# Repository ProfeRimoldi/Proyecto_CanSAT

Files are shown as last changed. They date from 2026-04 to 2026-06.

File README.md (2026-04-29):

# Proyecto CanSat – Base Aérea El Palomar

Sistema electrónico para misión tipo CanSat desarrollado en la EEST N°4 I Brigada Aérea El Palomar, orientado al diseño, validación y documentación de hardware y firmware para sistemas embarcados aeroespaciales.

Este repositorio centraliza el desarrollo de:

* Onboard Computer (OBC)
* Earth Station Dev Board
* Firmware ESP32
* Documentación técnica
* Revisiones de fabricación de PCB

---

## Estructura del proyecto

```text
Proyecto_CanSAT/
├── hardware/
│   ├── Onboard_Comp/
│   │   ├── kicad/
│   │   ├── outputs/
│   │   │   └── Rev_A/
│   │   └── docs/
│   │
│   └── Earth_Station/
│       ├── kicad/
│       ├── outputs/
│       └── docs/
│
├── firmware/
│
├── docs/
│
└── README.md
```

---

## Hardware

### Onboard Computer (OBC)

Computadora principal embarcada encargada de:

* adquisición de sensores
* telemetría
* control de misión
* gestión de eventos de vuelo
* integración con estación terrestre

Actualmente cuenta con:

* diseño PCB en KiCad
* esquemático jerárquico
* revisión formal de fabricación `Rev_A`
* Gerbers
* Drill files
* BOM
* PDF de esquemático
* renders e imágenes técnicas

---

### Earth Station Dev Board

Placa de desarrollo para estación terrestre destinada a:

* recepción de telemetría
* configuración de parámetros
* validación de comunicaciones
* integración de subsistemas

Actualmente cuenta con:

* diseño PCB en KiCad
* documentación estructurada
* revisión formal de fabricación `Rev_A`
* Gerbers
* Drill files
* BOM
* PDF de esquemático
* renders e imágenes técnicas

---

## Firmware

Desarrollo basado en ESP32 para:

* adquisición de datos
* control de sensores
* comunicaciones
* telemetría
* lógica de misión

Actualmente cuenta con:

* Firmware Test, verificador de enlace de comunicación LoRa entre los módulos.
* Muestra en pantalla, firmware dedicado a enviar los datos de aceleración en 3 ejes, y un código en Processing para visualizarlo.
* TestLED, para verificar el funcionamiento de los periféricos en la Earth Station Dev Board.

La estructura de firmware se encuentra en evolución y será versionada junto con las revisiones de hardware.

---

## Gestión de revisiones

Las revisiones de fabricación se organizan mediante:

```text
outputs/Rev_A/
outputs/Rev_B/
outputs/Rev_C/
```

permitiendo trazabilidad completa entre:

* diseño fuente
* fabricación real
* validaciones de laboratorio
* mejoras de revisión

---

## Objetivo

Mantener una metodología de desarrollo profesional para proyectos electrónicos aeroespaciales, con trazabilidad completa de hardware, firmware y documentación técnica.

---

## Autor

Damián Rimoldi
Ingeniería Electrónica – UTN FRH
GLT – Grupo de Lanzadores Tecnológicos
EEST N°4 I Brigada Aérea El Palomar

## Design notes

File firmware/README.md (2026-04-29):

# Firmware – Proyecto CanSat

Esta carpeta contiene el desarrollo de firmware y software auxiliar utilizado para validación, pruebas de laboratorio y futuras implementaciones del sistema CanSat.

Actualmente se incluyen códigos base, pruebas funcionales y herramientas de visualización para distintos subsistemas del proyecto.

---

## Contenido actual

```text
firmware/
├── EMISOR.ino
├── RECEPTOR.ino
├── CodBase.ino
├── TestLED.ino
├── Ver1.pde
└── README.md
```

---

## Descripción de archivos

---

### EMISOR.ino

Código de prueba para transmisión LoRa utilizando ESP32 + módulo SX1278 (433 MHz).

### Función

Permite enviar datos por comunicación LoRa desde la estación emisora hacia el receptor.

### Características

* inicialización de módulo LoRa
* frecuencia configurada en 433 MHz
* transmisión de mensajes desde monitor serie
* envío automático de secuencia numérica incremental
* validación básica de enlace inalámbrico

### Objetivo

Verificar estabilidad y alcance inicial de la comunicación LoRa entre nodos.

---

### RECEPTOR.ino

Código de prueba para recepción LoRa utilizando ESP32 + módulo SX1278 (433 MHz).

### Función

Recibe paquetes enviados por el transmisor y los muestra por puerto serie.

### Características

* inicialización de receptor LoRa
* recepción de paquetes
* reconstrucción de mensajes
* monitoreo por Serial Monitor

### Objetivo

Validar la recepción correcta de telemetría y pruebas de enlace.

---

### CodBase.ino

Código base para adquisición de datos utilizando sensor MPU6050 + ESP32.

### Función

Lee aceleración y velocidad angular del MPU6050 y transmite los datos por puerto serie.

### Características

* lectura de acelerómetro
* lectura de giroscopio
* integración temporal de velocidades angulares
* cálculo de ángulos acumulados
* envío de datos seriales en formato CSV

### Variables transmitidas

* aceleración X
* aceleración Y
* aceleración Z
* ángulo X
* ángulo Y
* ángulo Z

### Objetivo

Base de pruebas para sistemas de navegación, orientación e inclinación del vehículo.

---

### Ver1.pde

Visualización 3D en Processing para representación de orientación del sistema.

### Función

Recibe datos seriales desde el ESP32 y representa gráficamente la inclinación del cohete en tiempo real.

### Características

* comunicación serial con Processing
* lectura de datos CSV
* suavizado mediante filtro simple
* representación 3D con entorno P3D
* simulación visual del movimiento del cohete

### Objetivo

Visualizar rápidamente el comportamiento dinámico del sistema durante pruebas de sensores.

---

### TestLED.ino

Código de testeo funcional para la Earth Station Dev Board.

### Función

Permite verificar salidas digitales, buzzer, relay y conexiones principales de la placa.

### Características

* test secuencial de GPIOs
* activación progresiva de pines
* validación visual y sonora
* múltiples velocidades de prueba
* chequeo de líneas asociadas a GPS, MPU, buzzer y relay

### Objetivo

Confirmar funcionamiento eléctrico inicial de la placa fabricada.

---

## Próximas etapas

El firmware definitivo evolucionará hacia:

* máquina de estados de misión
* adquisición de sensores de vuelo
* altimetría
* detección de eventos (ignición, apogeo, despliegue)
* telemetría LoRa
* almacenamiento de datos
* comunicación con estación terrestre
* lógica de seguridad redundante

---

## Objetivo general

Mantener trazabilidad y evolución progresiva del firmware desde pruebas iniciales hasta la versión final de vuelo.

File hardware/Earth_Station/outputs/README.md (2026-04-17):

# Outputs - Earth Station

Esta carpeta contiene los archivos de fabricación y exportación del PCB de la Earth Station Dev Board.

## Estructura

### Rev_A

Primera revisión formal de fabricación de la placa.

Contenido esperado:

- Gerbers
- Drill files
- PDF del esquemático
- Imágenes del PCB
- BOM (Bill of Materials)

## Notas

Solo deben guardarse aquí versiones consolidadas listas para fabricación o revisión formal.

No utilizar esta carpeta para archivos temporales, backups automáticos o pruebas intermedias.

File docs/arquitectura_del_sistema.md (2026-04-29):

# Arquitectura del Sistema – Proyecto CanSat

## 1. Descripción general

El sistema CanSat se organiza en dos bloques principales:

* Onboard Computer (OBC)
* Earth Station Dev Board

El OBC corresponde al sistema embarcado, encargado de adquirir datos, procesar información de sensores, ejecutar la lógica de misión y transmitir telemetría.

La Earth Station Dev Board corresponde al sistema de tierra, orientado a recibir datos, visualizar información, validar comunicaciones y asistir durante pruebas de laboratorio o campo.

---

## 2. Bloques principales

### 2.1 Onboard Computer

Funciones principales:

* adquisición de sensores
* procesamiento de datos
* comunicación inalámbrica
* gestión de eventos de misión
* almacenamiento o transmisión de telemetría
* integración con firmware ESP32

### 2.2 Earth Station Dev Board

Funciones principales:

* recepción de telemetría
* monitoreo de datos
* pruebas de enlace LoRa
* asistencia durante validaciones
* interfaz con computadora o sistema de visualización

---

## 3. Arquitectura funcional

```text
[Sensores] 
    ↓
[Onboard Computer - ESP32]
    ↓
[Comunicación LoRa]
    ↓
[Earth Station Dev Board]
    ↓
[PC / Visualización / Registro]
```

---

## 4. Relación hardware-firmware

El hardware proporciona las interfaces físicas necesarias para sensores, comunicación, alimentación y señales auxiliares.

El firmware define el comportamiento lógico del sistema, incluyendo:

* inicialización de periféricos
* lectura de sensores
* procesamiento de datos
* comunicación LoRa
* lógica de misión
* gestión de estados
* transmisión de telemetría

---

## 5. Estado actual

Actualmente el proyecto cuenta con:

* PCB del Onboard Computer fabricada y documentada como `Rev_A`
* PCB de Earth Station fabricada y documentada como `Rev_A`
* firmware de prueba para LoRa, sensores y visualización
* validación de comunicación LoRa
* documentación inicial de arquitectura y trazabilidad

---

## 6. Próximas etapas

Las próximas etapas técnicas incluyen:

* consolidar firmware base
* definir máquina de estados de misión
* integrar sensores principales
* registrar pruebas de laboratorio
* documentar cambios entre revisiones
* avanzar hacia una versión estable de vuelo

---

## 7. Objetivo de arquitectura

Definir una estructura clara que permita evolucionar el sistema desde pruebas parciales hacia un sistema integrado, manteniendo trazabilidad entre diseño electrónico, firmware, fabricación y validación experimental.

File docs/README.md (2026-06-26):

# Documentation – Proyecto CanSat

Esta carpeta contiene la documentación técnica principal del proyecto, incluyendo arquitectura general del sistema, criterios de diseño, requerimientos, validaciones y evolución del desarrollo.

Aquí se concentra la trazabilidad técnica global entre hardware, firmware y validaciones experimentales.

---

## Contenido esperado

* arquitectura general del sistema
* requerimientos funcionales
* máquina de estados de misión
* plan de validación y ensayos
* decisiones de diseño
* criterios de seguridad
* cronograma de desarrollo
* informes técnicos.
* documentación de revisiones.

---

## Objetivo

Mantener una metodología de desarrollo profesional orientada a proyectos electrónicos aeroespaciales, permitiendo reconstruir decisiones técnicas, justificar revisiones y facilitar futuras iteraciones del sistema.

La documentación debe acompañar al hardware y firmware, no aparecer únicamente al final del proyecto.

---

## Relación con otras carpetas

* `hardware/` → diseño fuente y fabricación de PCB
* `firmware/` → desarrollo de software embbido
* `docs/` → documentación técnica global del sistema

---

## Nota importante

Cada cambio importante de hardware o firmware deberás tener su respaldo técnico correspondiente en esta carpeta.

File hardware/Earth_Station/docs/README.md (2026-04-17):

# Documentation - Earth Station

Esta carpeta contiene documentación técnica complementaria del proyecto.

## Contenido esperado

- decisiones de diseño
- notas de ingeniería
- cambios importantes entre revisiones
- cálculos relevantes
- validaciones y pruebas
- observaciones de fabricación
- incidencias detectadas en laboratorio

## Objetivo

Mantener trazabilidad técnica del desarrollo del hardware y facilitar futuras revisiones o rediseños.

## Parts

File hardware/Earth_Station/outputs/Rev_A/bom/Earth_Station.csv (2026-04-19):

Reference | Value | Datasheet | Footprint | Qty | DNP
BZ1 | Buzzer |  | Buzzer_Beeper:Buzzer_TDK_PS1240P02BT_D12.2mm_H6.5mm | 1
C1,C4,C5,C6 | 100nF |  | Capacitor_SMD:C_0805_2012Metric | 4
C2 | 100uF |  | Capacitor_SMD:CP_Elec_5x3 | 1
C3 | 10uF |  | Capacitor_SMD:CP_Elec_5x3.9 | 1
D1,D2,D3,D4,D5,D6,D7,D8,D9,D11 | LED |  | LED_SMD:LED_0805_2012Metric_Pad1.15x1.40mm_HandSolder | 10
D10 | 1N4148 | https://assets.nexperia.com/documents/data-sheet/1N4148_1N4448.pdf | Diode_THT:D_DO-35_SOD27_P7.62mm_Horizontal | 1
D12 | SS34 | https://www.vishay.com/docs/88751/ss32.pdf | Diode_SMD:D_3220_8050Metric_Pad2.65x5.15mm_HandSolder | 1
esp1,esp32_1 | Conn_01x19_Pin |  | Connector_PinSocket_2.54mm:PinSocket_1x19_P2.54mm_Vertical | 2
J1,J9 | SOCKET_UP |  | Connector_PinSocket_2.54mm:PinSocket_1x02_P2.54mm_Vertical,Connector_PinSocket_2.54mm:PinSocket_1x12_P2.54mm_Vertical | 2
J2 | Screw_Terminal_01x03 |  | TerminalBlock:TerminalBlock_bornier-3_P5.08mm | 1
J3,J5 | Conn_01x08 |  | Connector_PinSocket_2.54mm:PinSocket_1x08_P2.54mm_Vertical | 2
J4,J8,J12 | PLACA |  | Connector_PinHeader_1.27mm:PinHeader_1x02_P1.27mm_Vertical,Connector_PinHeader_1.27mm:PinHeader_1x12_P1.27mm_Vertical | 3
J6 | Conn_01x04 |  | Connector_PinSocket_2.54mm:PinSocket_1x04_P2.54mm_Vertical | 1
J7 | HEADER_DOWN |  | Connector_PinHeader_2.54mm:PinHeader_1x02_P2.54mm_Vertical | 1
J15 | Screw_Terminal_01x02 |  | TerminalBlock:TerminalBlock_bornier-2_P5.08mm | 1
J16 | Conn_01x02 |  | Connector_PinSocket_2.54mm:PinSocket_1x02_P2.54mm_Vertical | 1
K1 | Relay_SPDT |  | Relay_THT:Relay_SPDT_Finder_36.11 | 1
Q1 | NPN | https://ngspice.sourceforge.io/docs/ngspice-html-manual/manual.xhtml#cha_BJTs | Package_TO_SOT_THT:TO-92L_Inline | 1
R1,R2,R3,R4,R5,R6,R7,R8,R9,R10,R11,R12,R15 | 1K |  | Resistor_SMD:R_0805_2012Metric_Pad1.20x1.40mm_HandSolder | 13
R13,R14 | R |  | Resistor_SMD:R_0805_2012Metric,Resistor_SMD:R_0805_2012Metric_Pad1.20x1.40mm_HandSolder | 2
SW1 | SW_SPDT |  | Button_Switch_THT:SW_Slide_SPDT_Straight_CK_OS102011MS2Q | 1
SW2,SW3,SW4 | SW_Push_Dual |  | Button_Switch_SMD:SW_Push_1P1T_NO_Vertical_Wuerth_434133025816 | 3
U1,U2 | LM324A | http://www.ti.com/lit/ds/symlink/lm2902-n.pdf | Package_SO:SOIC-14_3.9x8.7mm_P1.27mm | 2
U3 | L7805 | http://www.st.com/content/ccc/resource/technical/document/datasheet/41/4f/b3/b0/12/d4/47/88/CD00000444.pdf/files/CD00000444.pdf/jcr:content/translations/en.CD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 | Package_TO_SOT_SMD:TO-263-2 | 1

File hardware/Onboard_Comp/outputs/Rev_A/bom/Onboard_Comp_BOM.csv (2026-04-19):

Reference | Value | Datasheet | Footprint | Qty | DNP
BZ1 | Buzzer |  | Buzzer_Beeper:Buzzer_TDK_PS1240P02BT_D12.2mm_H6.5mm | 1
C1 | 100nF |  | Capacitor_SMD:C_0805_2012Metric | 1
C2 | 100uF |  | Capacitor_SMD:CP_Elec_5x3.9 | 1
C3 | C_Polarized_Small |  | Capacitor_SMD:C_0805_2012Metric | 1
D1 | LED |  | LED_SMD:LED_0805_2012Metric_Pad1.15x1.40mm_HandSolder | 1
esp1,esp32_1 | Conn_01x19_Pin |  | Connector_PinSocket_2.54mm:PinSocket_1x19_P2.54mm_Vertical | 2
J1,J5,J9 | SOCKET_UP |  | Connector_PinSocket_2.54mm:PinSocket_1x02_P2.54mm_Vertical,Connector_PinSocket_2.54mm:PinSocket_1x12_P2.54mm_Vertical | 3
J2,J6,J10 | HEADER_UP |  | Connector_PinHeader_2.54mm:PinHeader_1x02_P2.54mm_Vertical,Connector_PinHeader_2.54mm:PinHeader_1x12_P2.54mm_Vertical | 3
J3,J7,J11 | HEADER_DOWN |  | Connector_PinHeader_2.54mm:PinHeader_1x02_P2.54mm_Vertical,Connector_PinHeader_2.54mm:PinHeader_1x12_P2.54mm_Vertical | 3
J4,J8,J12 | PLACA |  | Connector_PinHeader_1.27mm:PinHeader_1x02_P1.27mm_Vertical,Connector_PinHeader_1.27mm:PinHeader_1x12_P1.27mm_Vertical | 3
J13 | Conn_01x08_SocketMPU |  | Connector_PinSocket_2.54mm:PinSocket_1x08_P2.54mm_Vertical | 1
J14 | Conn_01x04_Socket |  | Connector_PinSocket_2.54mm:PinSocket_1x04_P2.54mm_Vertical | 1
J15 | Screw_Terminal_01x02 |  | TerminalBlock:TerminalBlock_bornier-2_P5.08mm | 1
J16,J18,J20,J21 | Conn_01x02 |  | Connector_PinHeader_2.54mm:PinHeader_1x02_P2.54mm_Vertical,Connector_PinSocket_2.54mm:PinSocket_1x02_P2.54mm_Vertical | 4
J17 | Conn_01x06_Socket |  | Connector_PinSocket_2.54mm:PinSocket_1x06_P2.54mm_Vertical | 1
J19 | Conn_01x03 |  | Connector_PinSocket_2.54mm:PinSocket_1x03_P2.54mm_Vertical | 1
R1 | 1K |  | Resistor_SMD:R_0805_2012Metric | 1
R2 | R |  | Resistor_SMD:R_0805_2012Metric_Pad1.20x1.40mm_HandSolder | 1
SW1 | SW_SPDT |  | Button_Switch_THT:SW_Slide_SPDT_Straight_CK_OS102011MS2Q | 1
U1 | 25CSM04xxSN | https://ww1.microchip.com/downloads/aemDocuments/documents/MPD/ProductDocuments/DataSheets/25CSM04-4-Mbit-SPI-Serial-EEPROM-With-128-Bit-Serial-Number-and-Enh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 | Package_SO:SOIC-8_5.23x5.23mm_P1.27mm | 1

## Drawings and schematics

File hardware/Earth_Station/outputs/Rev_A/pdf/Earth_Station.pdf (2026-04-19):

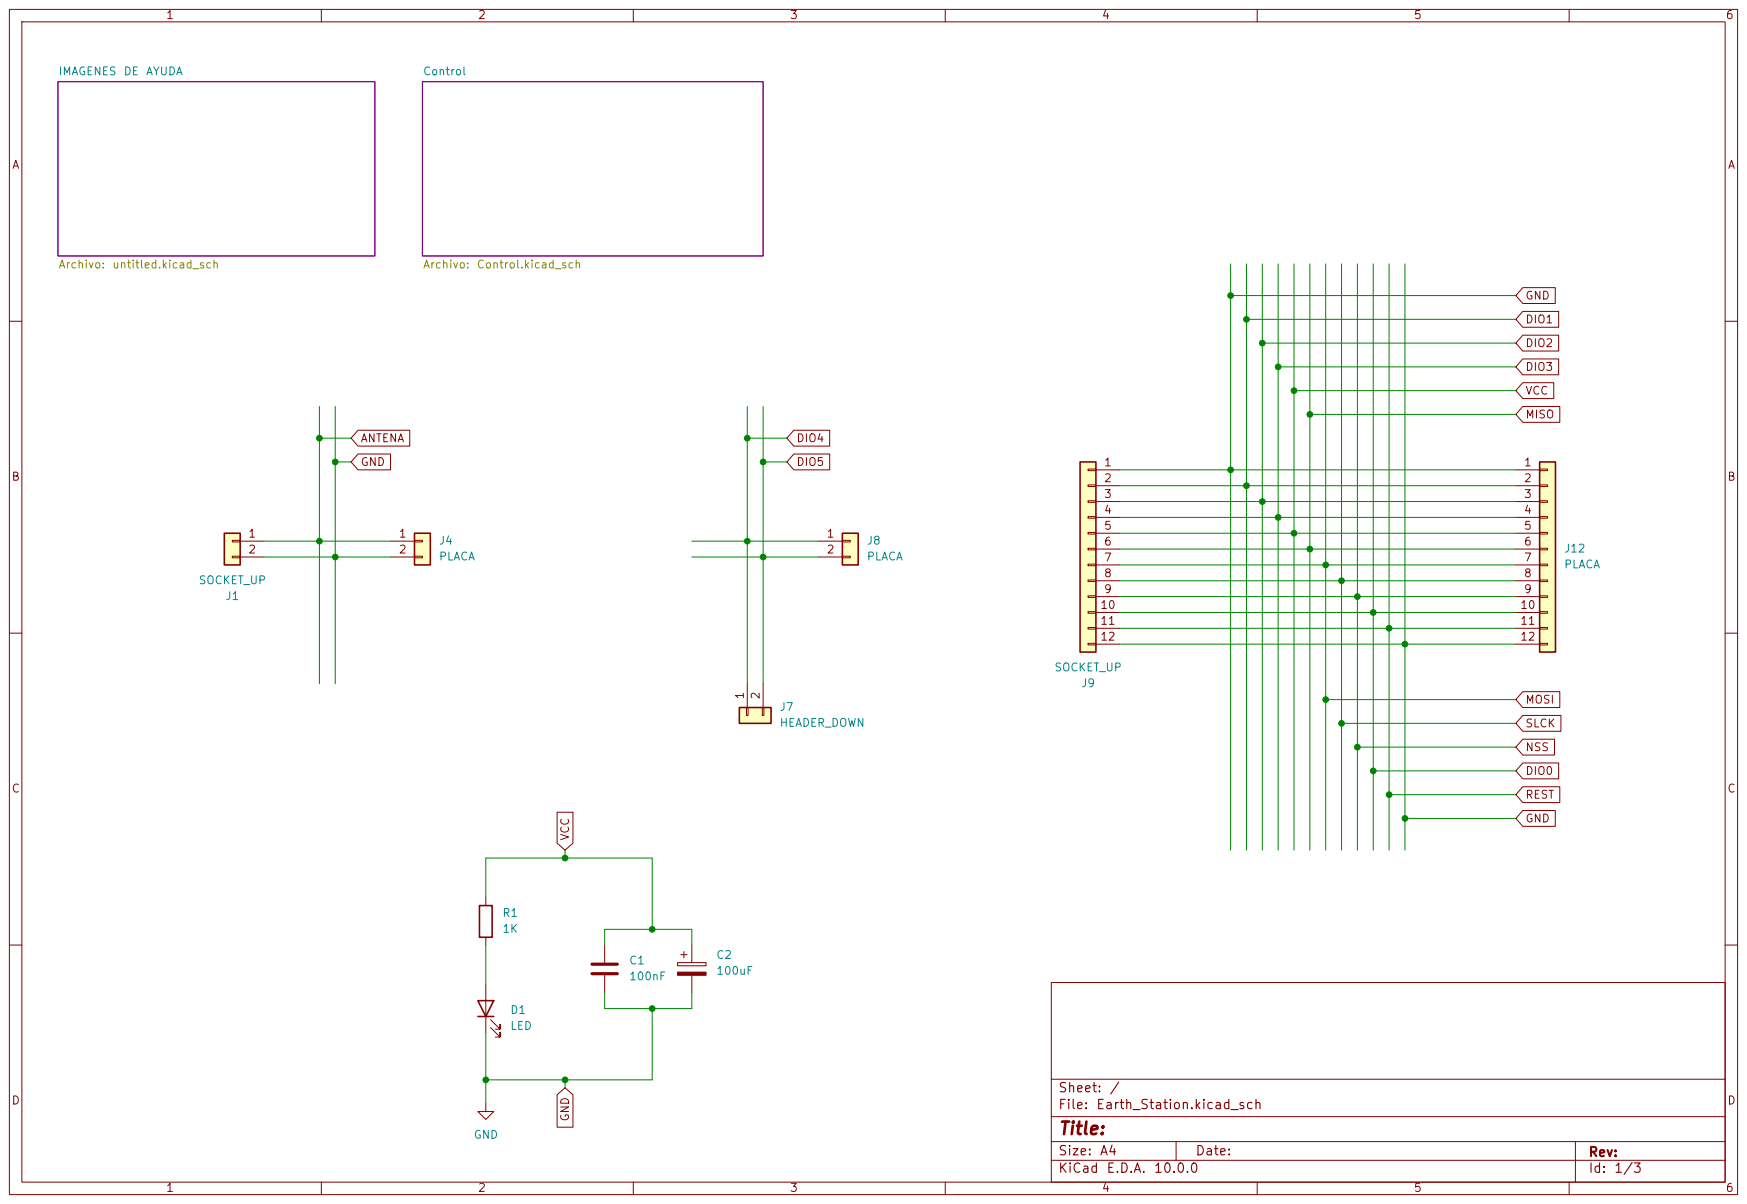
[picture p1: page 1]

10 | 10
11 | 11
12 | 12

Size: A4 | Rev:
KiCad E.D.A. 10.0.0 | Id: 1/3

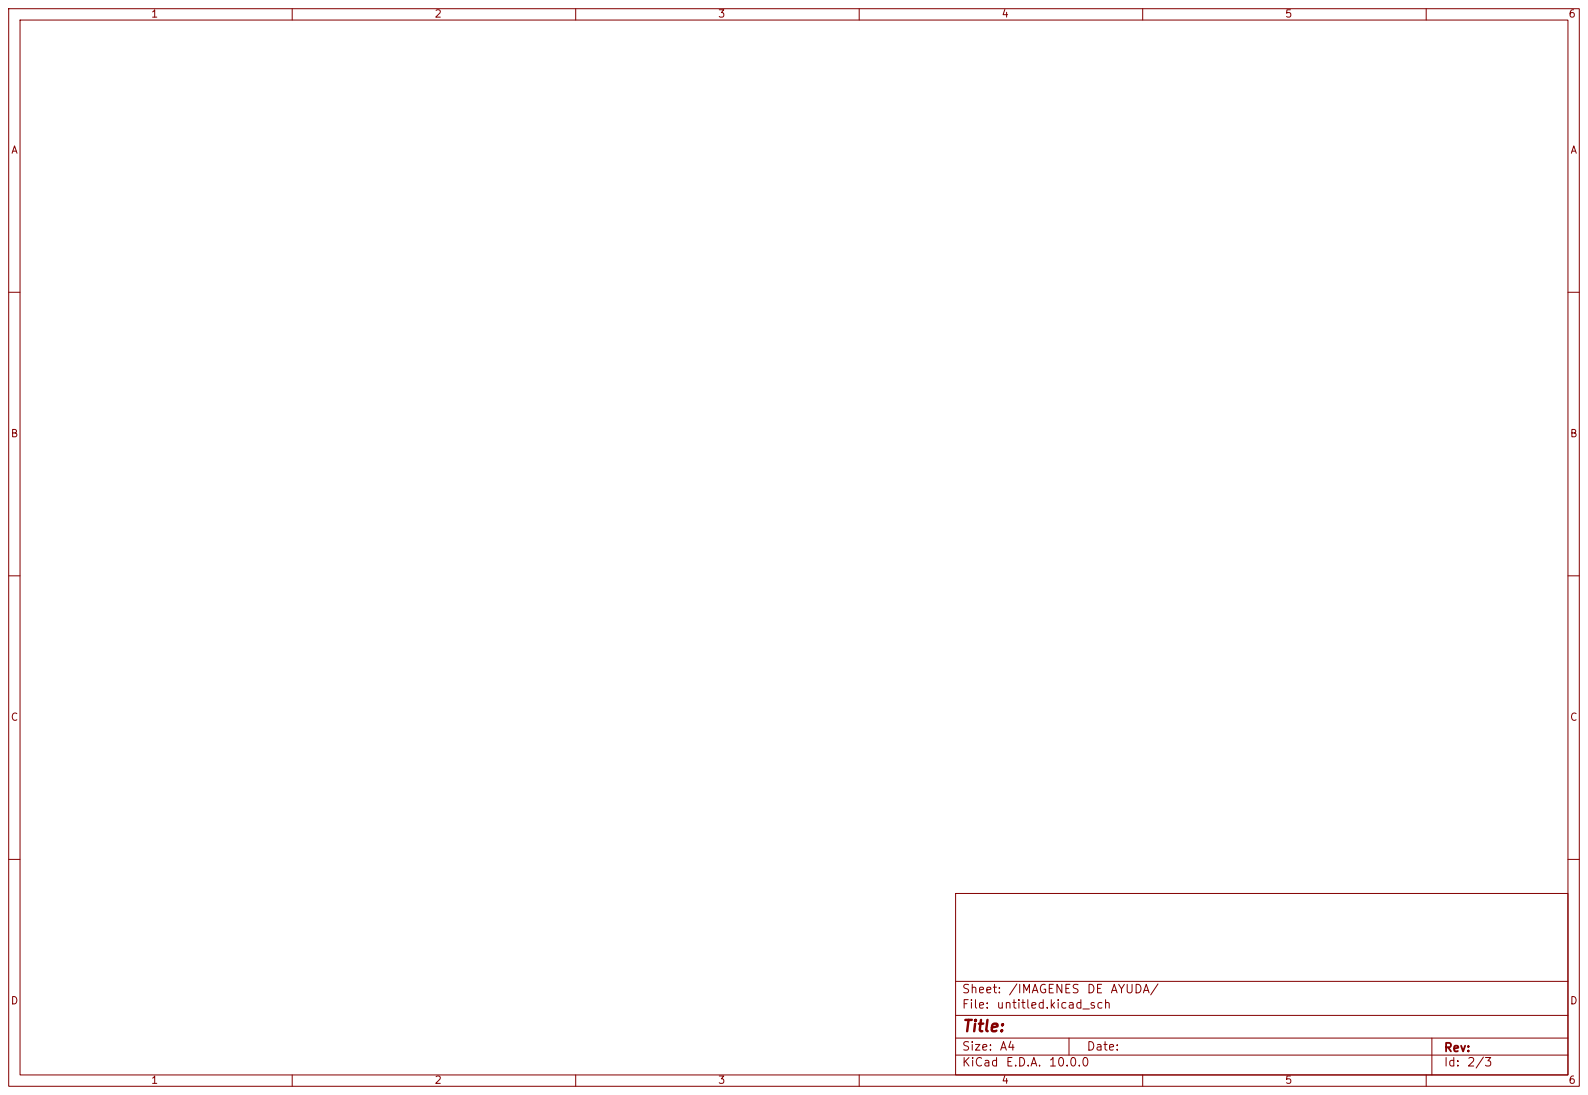
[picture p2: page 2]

Sheet: /IMAGENES DE AYUDA/
File: untitled.kicad_sch
Title:

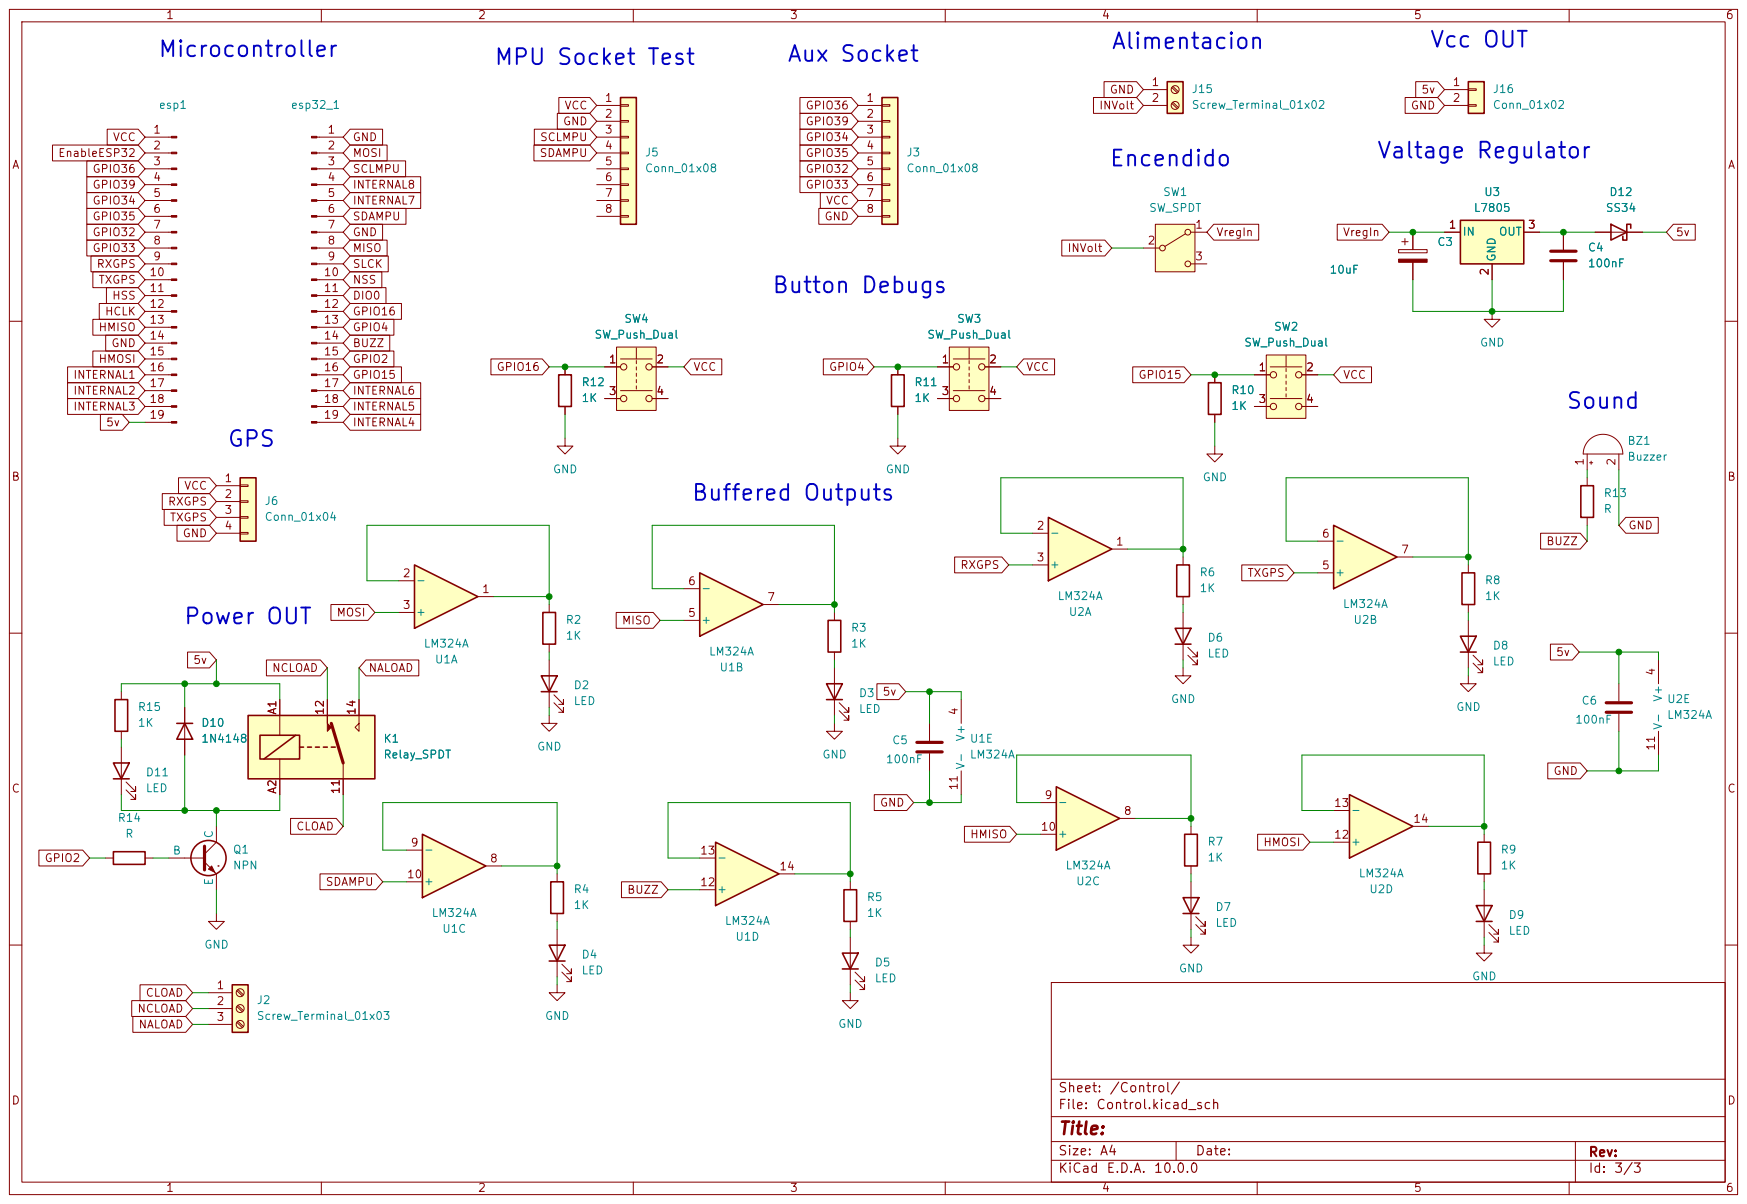
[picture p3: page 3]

VCC HCLK HSS HMISO

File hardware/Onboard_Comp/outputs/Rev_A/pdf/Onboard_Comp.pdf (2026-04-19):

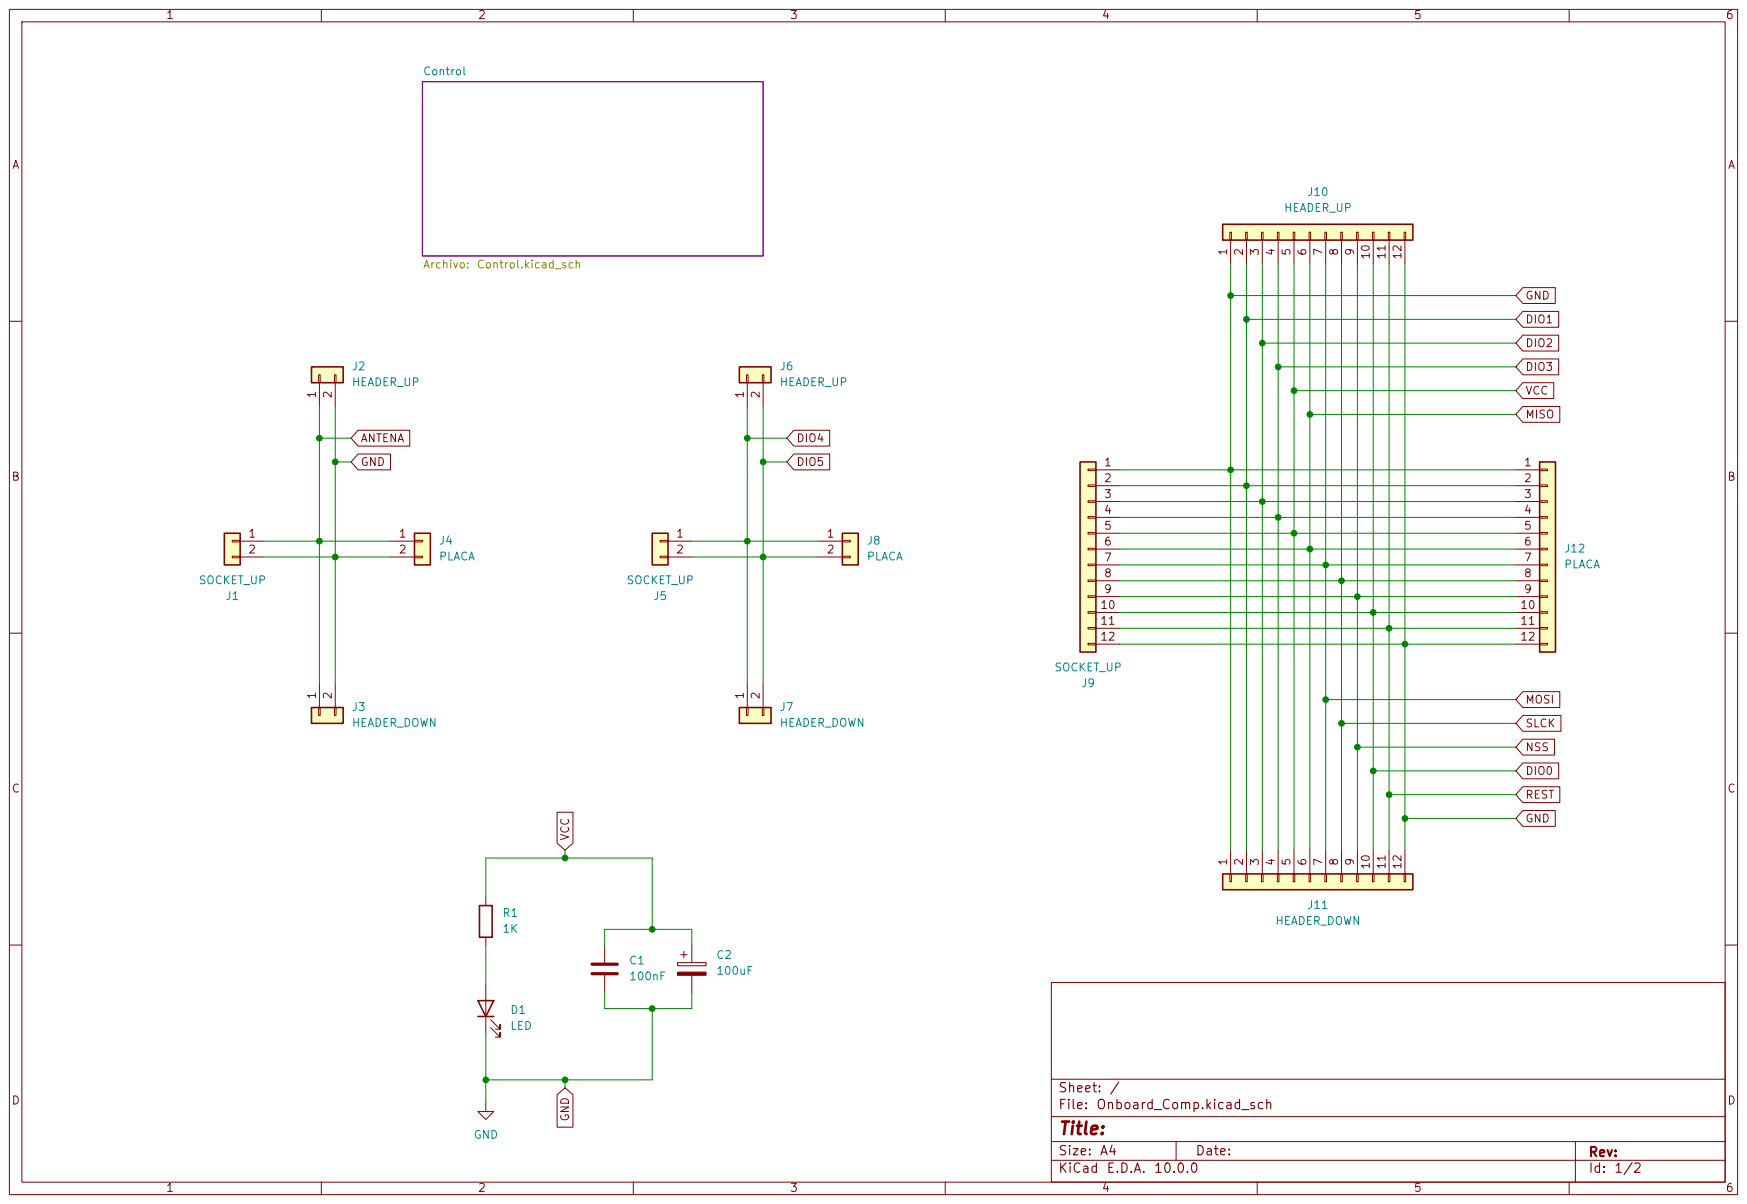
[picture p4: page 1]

J12 PLACA 1

10 | | 10
11 | | 11
12 | | 12

Size: A4 | Rev:
KiCad E.D.A. 10.0.0 | Id: 1/2

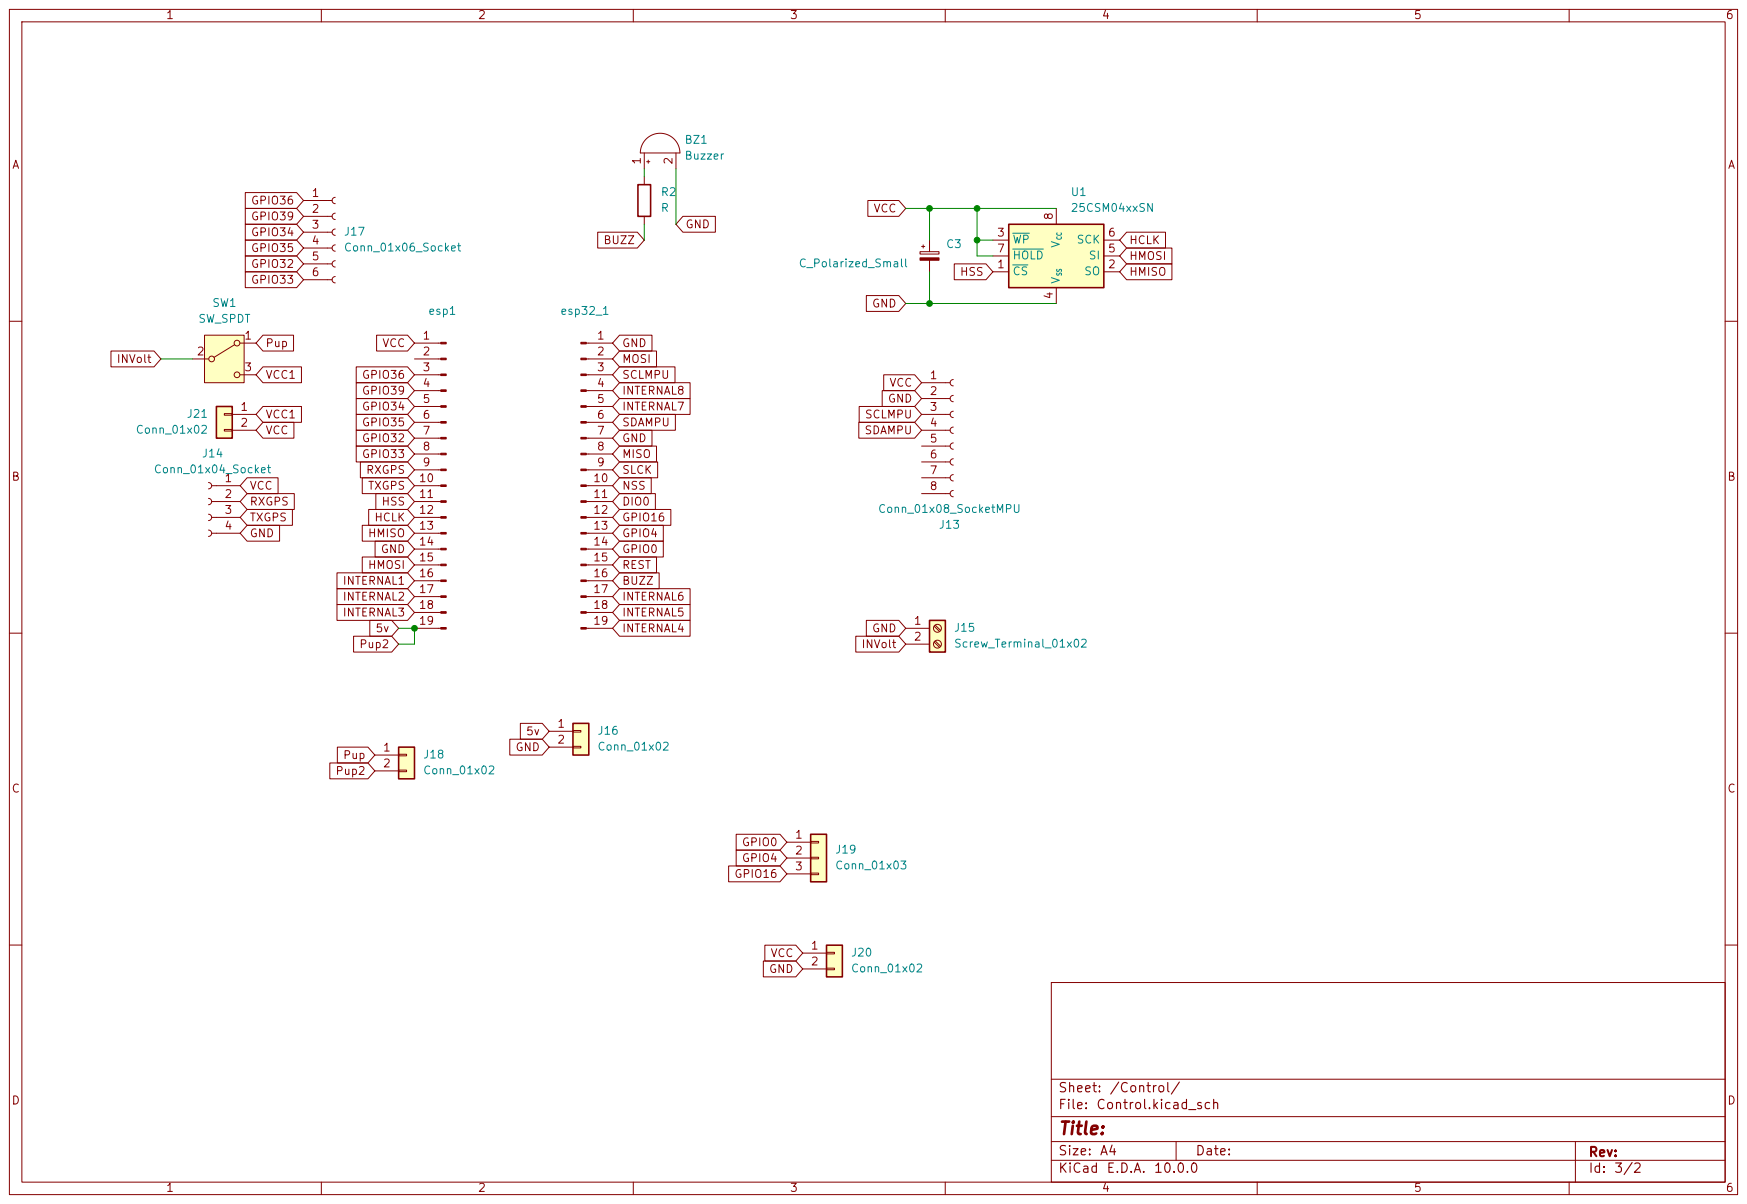
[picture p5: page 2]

Size: A4 | Rev:
KiCad E.D.A. 10.0.0 | Id: 3/2

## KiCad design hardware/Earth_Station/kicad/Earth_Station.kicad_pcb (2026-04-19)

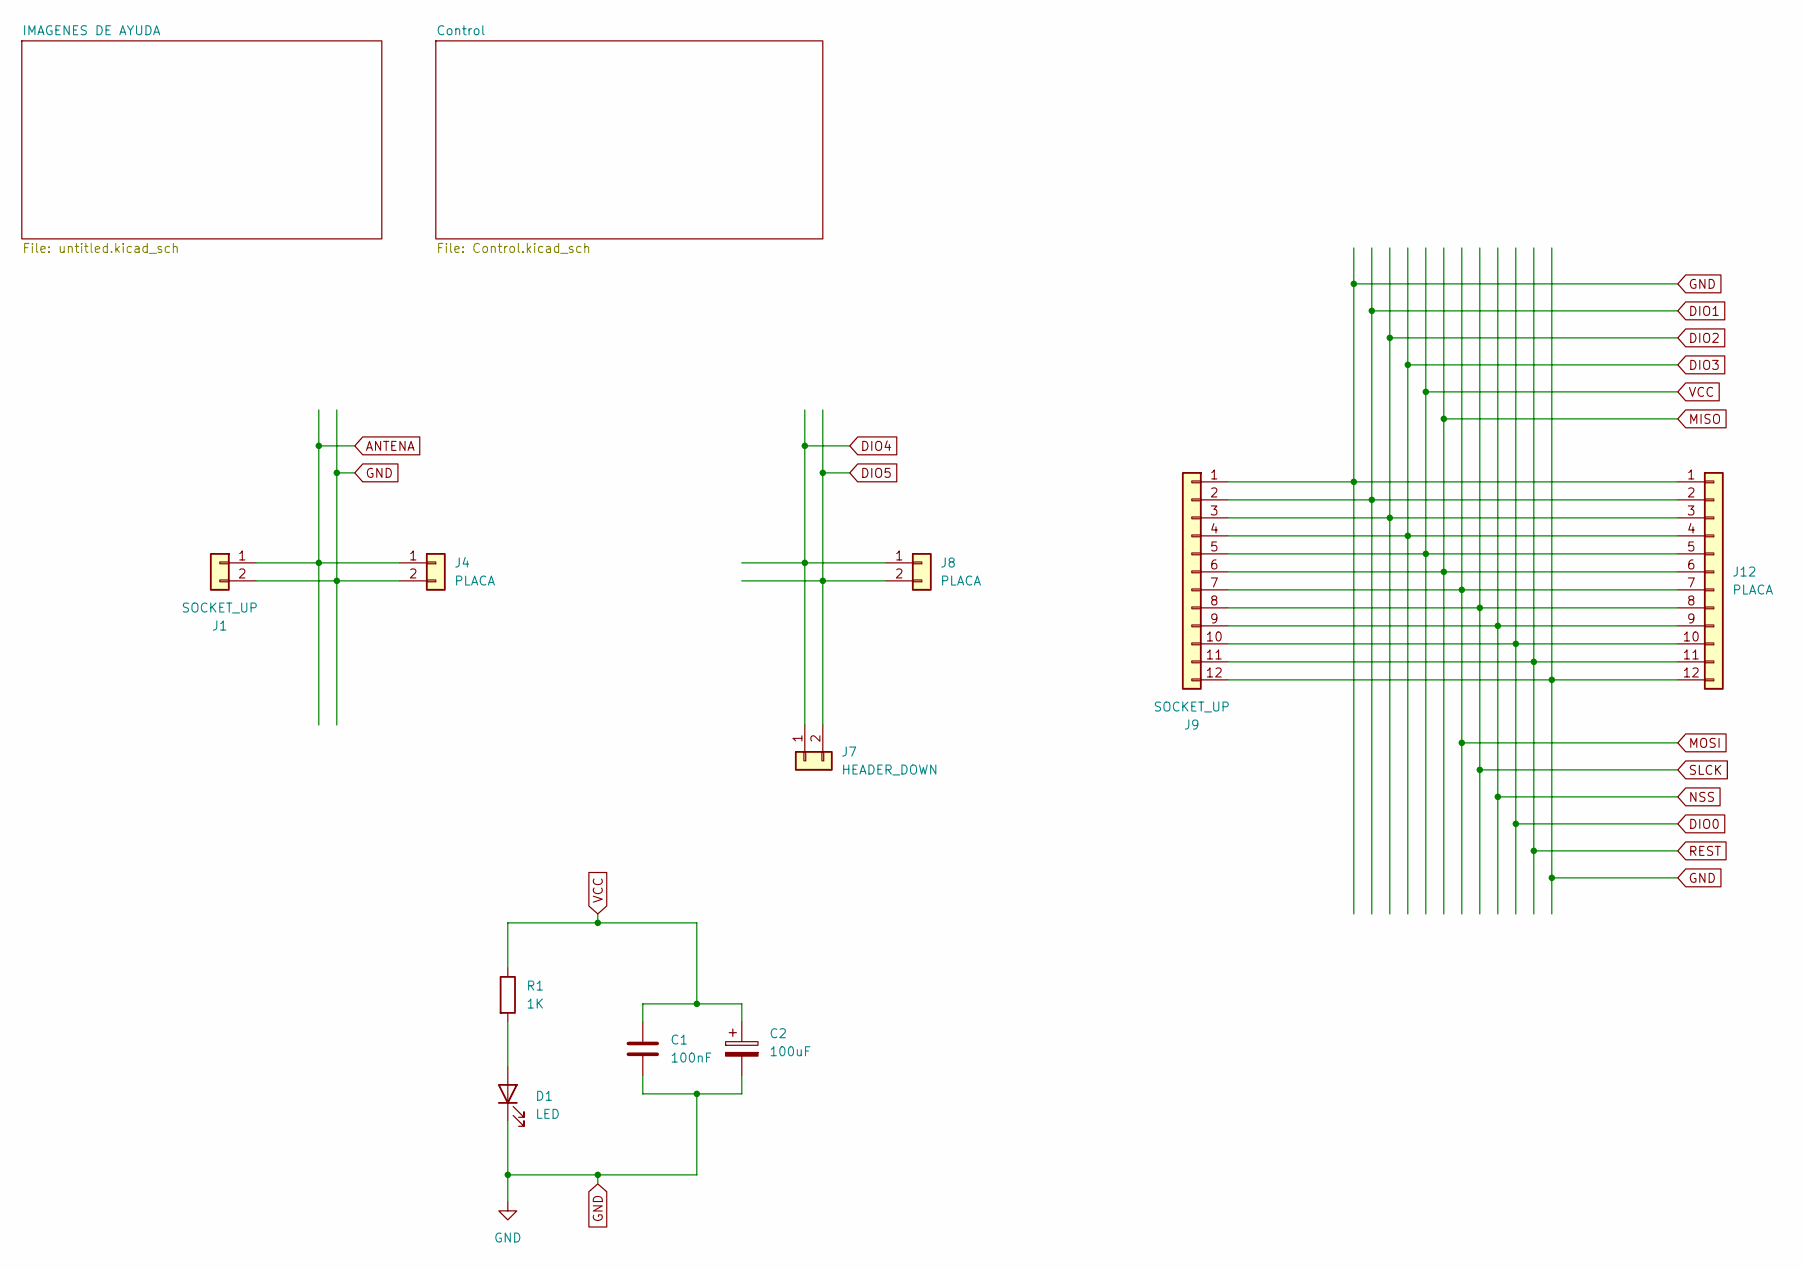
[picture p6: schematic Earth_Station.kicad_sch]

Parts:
C1: 100nF; C_0805_2012Metric
C2: 100uF; CP_Elec_5x3
D1: LED; LED_0805_2012Metric_Pad1.15x1.40mm_HandSolder
J1: SOCKET_UP; PinSocket_1x02_P2.54mm_Vertical
J4, J8: PLACA; PinHeader_1x02_P1.27mm_Vertical
J7: HEADER_DOWN; PinHeader_1x02_P2.54mm_Vertical
J9: SOCKET_UP; PinSocket_1x12_P2.54mm_Vertical
J12: PLACA; PinHeader_1x12_P1.27mm_Vertical
R1: 1K; R_0805_2012Metric_Pad1.20x1.40mm_HandSolder

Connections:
ANTENA: J1.1, J4.1
DIO0: J9.10, J12.10; also elsewhere on the board
DIO1: J9.2, J12.2
DIO2: J9.3, J12.3
DIO3: J9.4, J12.4
DIO4: J7.1, J8.1
DIO5: J7.2, J8.2
GND: C1.2, C2.2, D1.1 (K), J1.2, J4.2, J9.1, J9.12, J12.1, J12.12; also elsewhere on the board
MISO: J9.6, J12.6; also elsewhere on the board
MOSI: J9.7, J12.7; also elsewhere on the board
NSS: J9.9, J12.9; also elsewhere on the board
unnamed: D1.2 (A), R1.2
REST: J9.11, J12.11
SLCK: J9.8, J12.8; also elsewhere on the board
VCC: C1.1, C2.1, J9.5, J12.5, R1.1; also elsewhere on the board

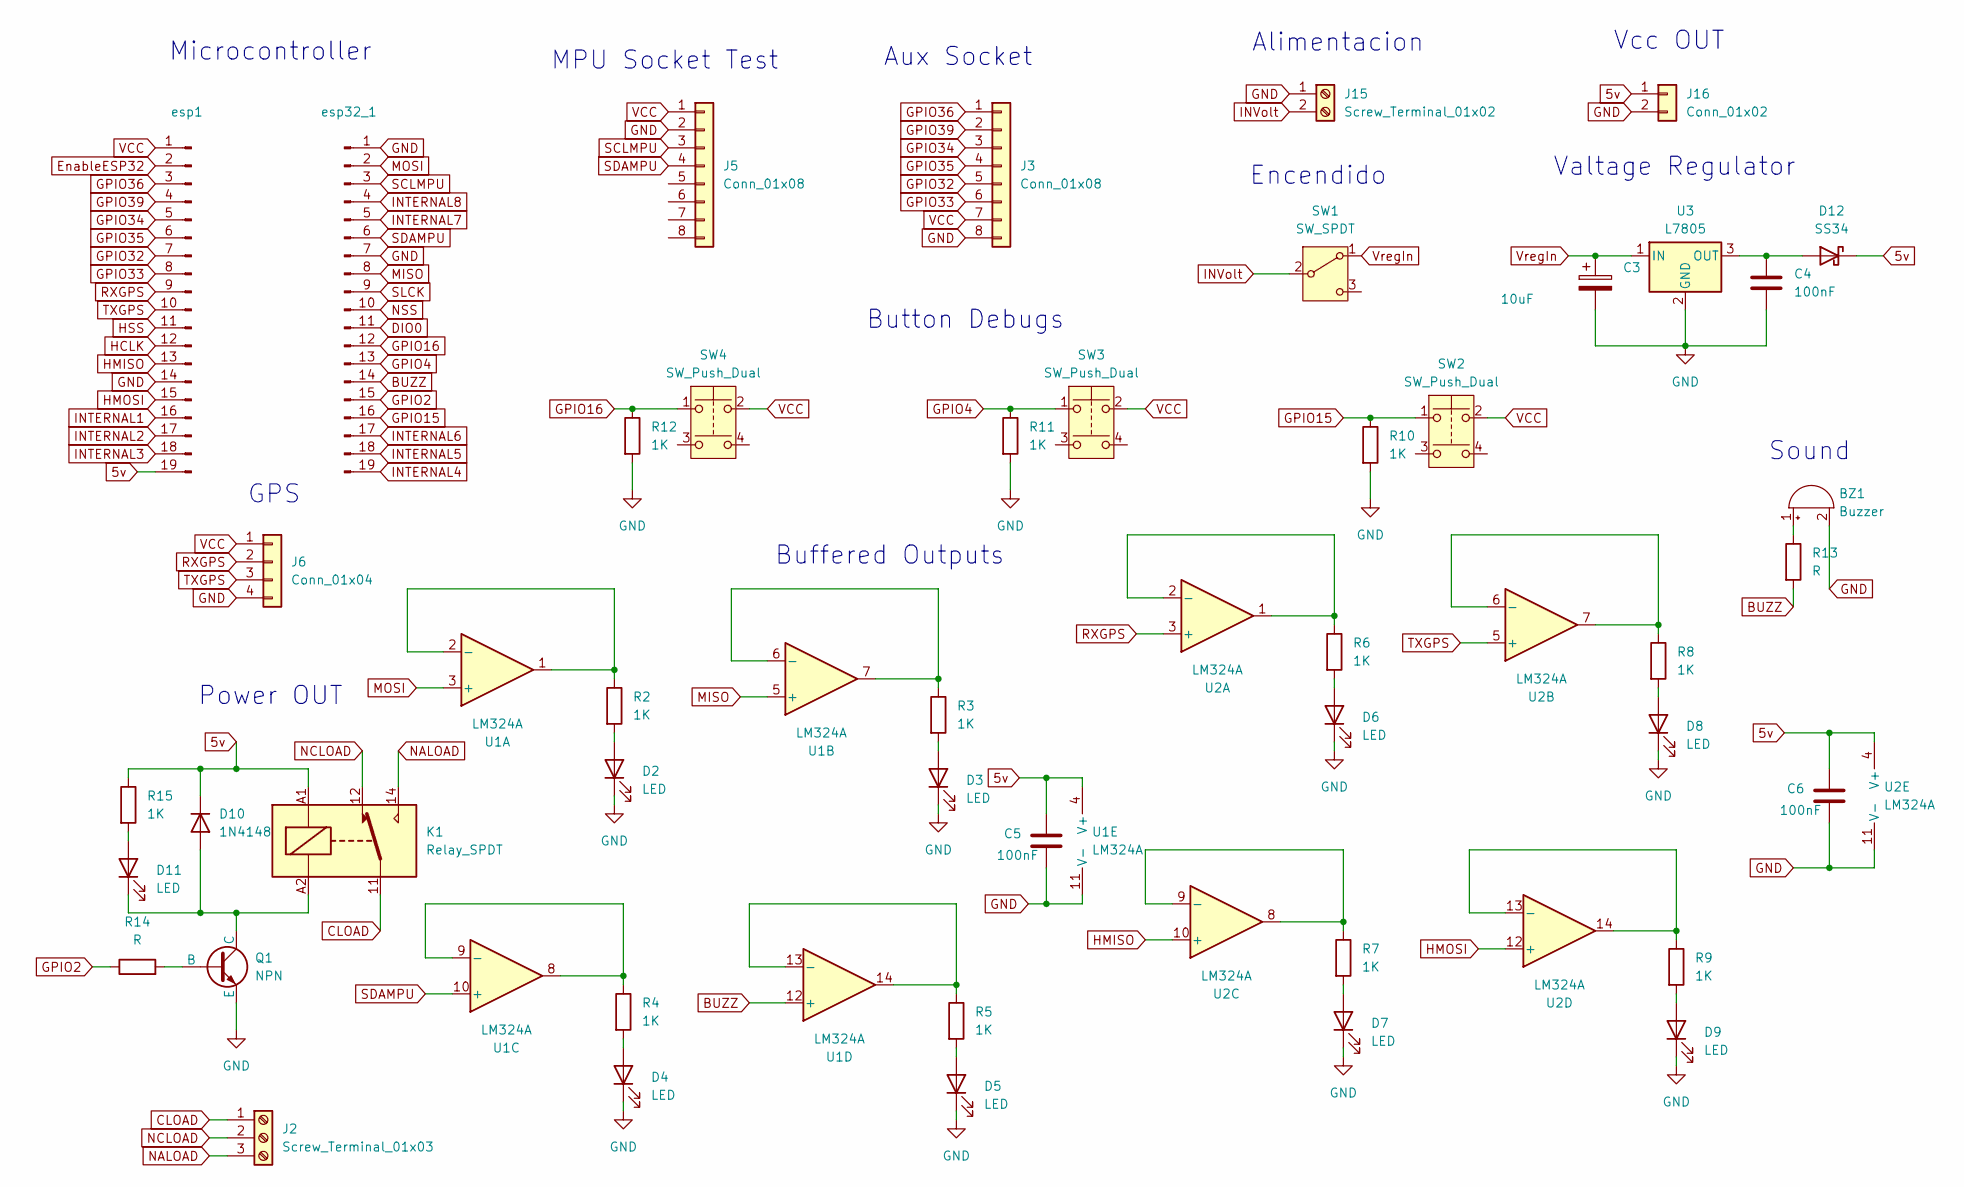
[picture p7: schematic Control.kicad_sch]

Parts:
BZ1: Buzzer; Buzzer_TDK_PS1240P02BT_D12.2mm_H6.5mm
C3: 10uF; CP_Elec_5x3.9
C4, C5, C6: 100nF; C_0805_2012Metric
D2, D3, D4, D5, D6, D7, D8, D9, D11: LED; LED_0805_2012Metric_Pad1.15x1.40mm_HandSolder
D10: 1N4148; D_DO-35_SOD27_P7.62mm_Horizontal
D12: SS34; D_3220_8050Metric_Pad2.65x5.15mm_HandSolder
J2: Screw_Terminal_01x03; TerminalBlock_bornier-3_P5.08mm
J3, J5: Conn_01x08; PinSocket_1x08_P2.54mm_Vertical
J6: Conn_01x04; PinSocket_1x04_P2.54mm_Vertical
J15: Screw_Terminal_01x02; TerminalBlock_bornier-2_P5.08mm
J16: Conn_01x02; PinSocket_1x02_P2.54mm_Vertical
K1: Relay_SPDT; Relay_SPDT_Finder_36.11
Q1: NPN; TO-92L_Inline
R2, R3, R4, R5, R6, R7, R8, R9, R10, R11, R12, R15: 1K; R_0805_2012Metric_Pad1.20x1.40mm_HandSolder
R13: R; R_0805_2012Metric_Pad1.20x1.40mm_HandSolder
R14: R; R_0805_2012Metric
SW1: SW_SPDT; SW_Slide_SPDT_Straight_CK_OS102011MS2Q
SW2, SW3, SW4: SW_Push_Dual; SW_Push_1P1T_NO_Vertical_Wuerth_434133025816
U1, U2: LM324A; SOIC-14_3.9x8.7mm_P1.27mm
U3: L7805; TO-263-2
esp1, esp32_1: Conn_01x19_Pin; PinSocket_1x19_P2.54mm_Vertical

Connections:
5v: C5.1, C6.1, D10.1 (K), D12.1 (K), J16.1, K1.A1, R15.1, U1.4 (V+), U2.4 (V+), esp1.19
BUZZ: R13.2, U1.12 (+), esp32_1.14
CLOAD: J2.1, K1.11
DIO0: esp32_1.11; also elsewhere on the board
EnableESP32: esp1.2
GND: BZ1.2 (-), C3.2, C4.2, C5.2, C6.2, D2.1 (K), D3.1 (K), D4.1 (K), D5.1 (K), D6.1 (K), D7.1 (K), D8.1 (K), D9.1 (K), J3.8, J5.2, J6.4, J15.1, J16.2, Q1.3 (E), R10.2, R11.2, R12.2, U1.11 (V-), U2.11 (V-), U3.2 (GND), esp1.14, esp32_1.1, esp32_1.7; also elsewhere on the board
GPIO2: R14.1, esp32_1.15
GPIO4: R11.1, SW3.1, esp32_1.13
GPIO15: R10.1, SW2.1, esp32_1.16
GPIO16: R12.1, SW4.1, esp32_1.12
GPIO32: J3.5, esp1.7
GPIO33: J3.6, esp1.8
GPIO34: J3.3, esp1.5
GPIO35: J3.4, esp1.6
GPIO36: J3.1, esp1.3
GPIO39: J3.2, esp1.4
HCLK: esp1.12
HMISO: U2.10 (+), esp1.13
HMOSI: U2.12 (+), esp1.15
HSS: esp1.11
INTERNAL1: esp1.16
INTERNAL2: esp1.17
INTERNAL3: esp1.18
INTERNAL4: esp32_1.19
INTERNAL5: esp32_1.18
INTERNAL6: esp32_1.17
INTERNAL7: esp32_1.5
INTERNAL8: esp32_1.4
INVolt: J15.2, SW1.2 (B)
MISO: U1.5 (+), esp32_1.8; also elsewhere on the board
MOSI: U1.3 (+), esp32_1.2; also elsewhere on the board
NALOAD: J2.3, K1.14
NCLOAD: J2.2, K1.12
NSS: esp32_1.10; also elsewhere on the board
unnamed: BZ1.1 (+), R13.1
unnamed: D2.2 (A), R2.2
unnamed: D3.2 (A), R3.2
unnamed: D4.2 (A), R4.2
unnamed: D5.2 (A), R5.2
unnamed: D6.2 (A), R6.2
unnamed: D7.2 (A), R7.2
unnamed: D8.2 (A), R8.2
unnamed: D9.2 (A), R9.2
unnamed: D10.2 (A), D11.1 (K), K1.A2, Q1.1 (C)
unnamed: D11.2 (A), R15.2
unnamed: C4.1, D12.2 (A), U3.3 (OUT)
unnamed: Q1.2 (B), R14.2
unnamed: R2.1, U1.1, U1.2 (-)
unnamed: R3.1, U1.6 (-), U1.7
unnamed: R4.1, U1.8, U1.9 (-)
unnamed: R5.1, U1.13 (-), U1.14
unnamed: R6.1, U2.1, U2.2 (-)
unnamed: R8.1, U2.6 (-), U2.7
unnamed: R7.1, U2.8, U2.9 (-)
unnamed: R9.1, U2.13 (-), U2.14
RXGPS: J6.2, U2.3 (+), esp1.9
SCLMPU: J5.3, esp32_1.3
SDAMPU: J5.4, U1.10 (+), esp32_1.6
SLCK: esp32_1.9; also elsewhere on the board
TXGPS: J6.3, U2.5 (+), esp1.10
VCC: J3.7, J5.1, J6.1, SW2.2, SW3.2, SW4.2, esp1.1; also elsewhere on the board
VregIn: C3.1, SW1.1 (A), U3.1 (IN)

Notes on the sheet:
Buffered Outputs
Microcontroller
GPS
Valtage Regulator
Vcc OUT
Encendido
Alimentacion
Aux Socket
MPU Socket Test
Button Debugs
Sound
Power OUT

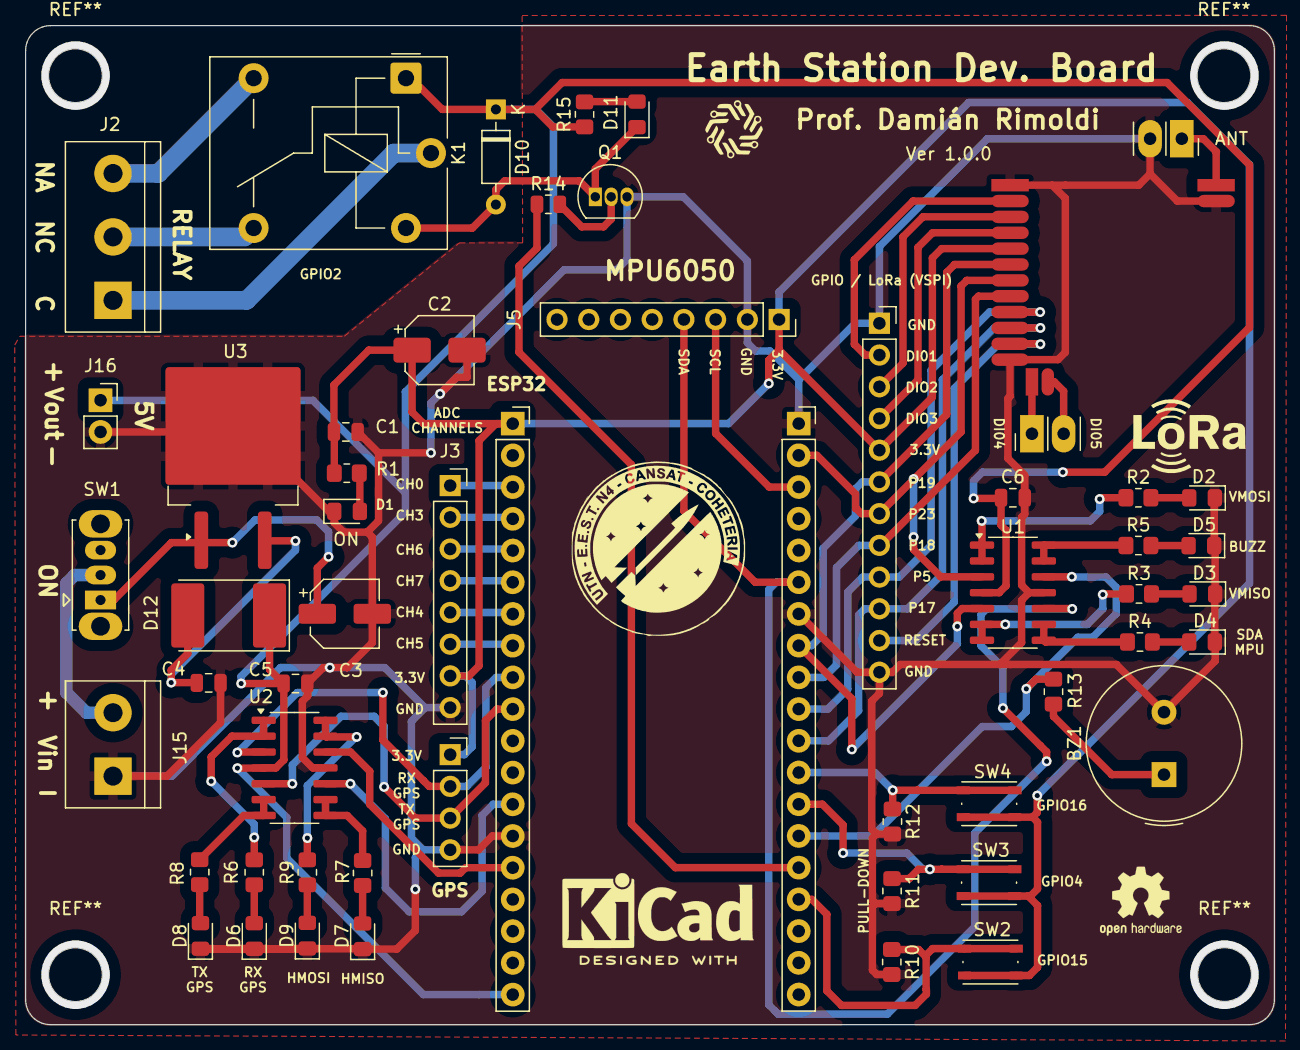
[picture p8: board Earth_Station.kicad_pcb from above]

Board: 2 copper layers, 100.0 x 80.0 mm, 57 parts (0 on the bottom side), 59 nets.

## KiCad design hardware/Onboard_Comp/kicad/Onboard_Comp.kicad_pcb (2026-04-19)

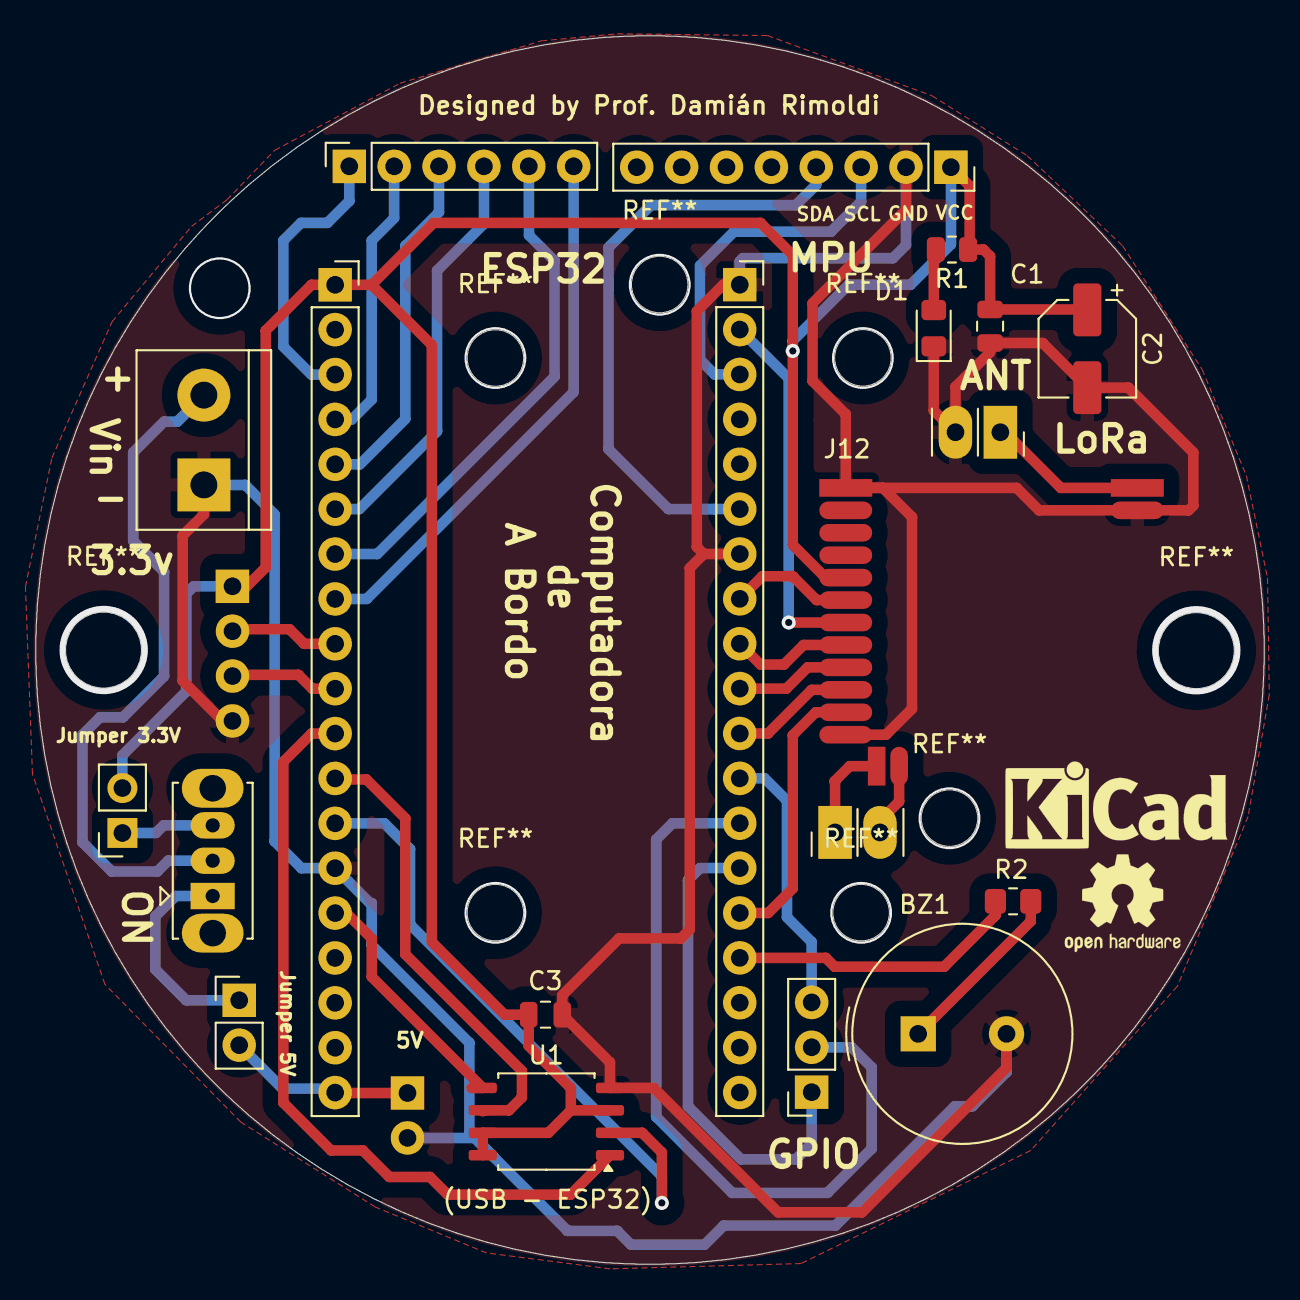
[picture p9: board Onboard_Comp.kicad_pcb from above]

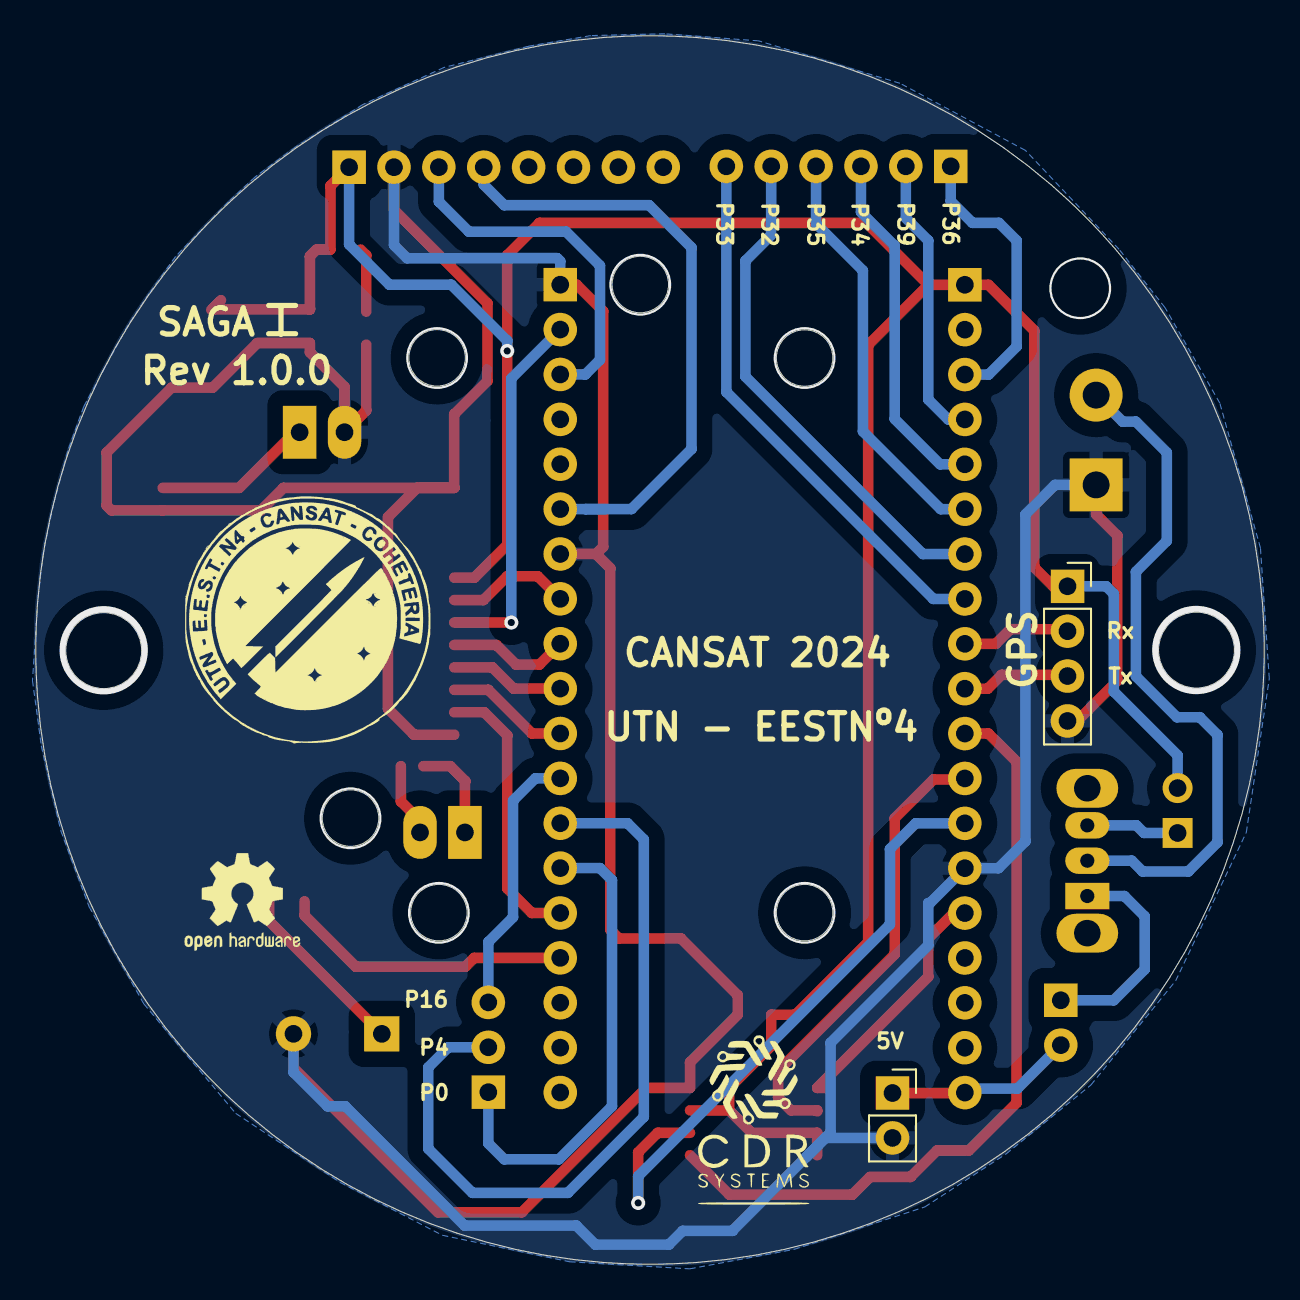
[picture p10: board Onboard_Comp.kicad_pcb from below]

Board: 2 copper layers, 69.5 x 69.5 mm, 24 parts (2 on the bottom side), 35 nets.

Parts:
BZ1: Buzzer; Buzzer_TDK_PS1240P02BT_D12.2mm_H6.5mm
C1: 100nF; C_0805_2012Metric
C2: 100uF; CP_Elec_5x3.9
C3: C_Polarized_Small; C_0805_2012Metric
D1: LED; LED_0805_2012Metric_Pad1.15x1.40mm_HandSolder
J1: SOCKET_UP; PinSocket_1x02_P2.54mm_Vertical
J4, J8: PLACA; PinHeader_1x02_P1.27mm_Vertical
J7: HEADER_DOWN; PinHeader_1x02_P2.54mm_Vertical
J12: PLACA; PinHeader_1x12_P1.27mm_Vertical
J13: Conn_01x08_SocketMPU; PinSocket_1x08_P2.54mm_Vertical
J14: Conn_01x04_Socket; PinSocket_1x04_P2.54mm_Vertical
J15: Screw_Terminal_01x02; TerminalBlock_bornier-2_P5.08mm
J16, J21: Conn_01x02; PinSocket_1x02_P2.54mm_Vertical
J17: Conn_01x06_Socket; PinSocket_1x06_P2.54mm_Vertical
J18: Conn_01x02; PinHeader_1x02_P2.54mm_Vertical
J19: Conn_01x03; PinSocket_1x03_P2.54mm_Vertical
R1: 1K; R_0805_2012Metric
R2: R; R_0805_2012Metric_Pad1.20x1.40mm_HandSolder
SW1: SW_SPDT; SW_Slide_SPDT_Straight_CK_OS102011MS2Q
U1: 25CSM04xxSN; SOIC-8_5.23x5.23mm_P1.27mm
esp1, esp32_1: Conn_01x19_Pin; PinSocket_1x19_P2.54mm_Vertical

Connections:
5v: J16.1, J18.2, esp1.19
ANTENA: J1.1, J4.1
BUZZ: R2.2, esp32_1.16
DIO0: J12.10, esp32_1.11
DIO4: J7.1, J8.1
DIO5: J7.2, J8.2
GND: BZ1.2 (-), C1.2, C2.2, C3.2, D1.1 (K), J1.2, J4.2, J12.1, J12.12, J13.2, J14.4, J15.1, J16.2, U1.4 (V_{SS}), esp1.14, esp32_1.1, esp32_1.7
GPIO0: J19.1, esp32_1.14
GPIO4: J19.2, esp32_1.13
GPIO16: J19.3, esp32_1.12
GPIO32: J17.5, esp1.7
GPIO33: J17.6, esp1.8
GPIO34: J17.3, esp1.5
GPIO35: J17.4, esp1.6
GPIO36: J17.1, esp1.3
GPIO39: J17.2, esp1.4
HCLK: U1.6 (SCK), esp1.12
HMISO: U1.2 (SO), esp1.13
HMOSI: U1.5 (SI), esp1.15
HSS: U1.1 (~CS), esp1.11
INVolt: J15.2, SW1.2 (B)
MISO: J12.6, esp32_1.8
MOSI: J12.7, esp32_1.2
NSS: J12.9, esp32_1.10
unnamed: BZ1.1 (+), R2.1
unnamed: D1.2 (A), R1.2
Pup: J18.1, SW1.1 (A)
REST: J12.11, esp32_1.15
RXGPS: J14.2, esp1.9
SCLMPU: J13.3, esp32_1.3
SDAMPU: J13.4, esp32_1.6
SLCK: J12.8, esp32_1.9
TXGPS: J14.3, esp1.10
VCC: C1.1, C2.1, C3.1, J12.5, J13.1, J14.1, J21.2, R1.1, U1.3 (~WP), U1.7 (~HOLD), U1.8 (V_{CC}), esp1.1
VCC1: J21.1, SW1.3 (C)

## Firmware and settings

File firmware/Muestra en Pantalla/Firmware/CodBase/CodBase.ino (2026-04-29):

/*
  Autor:  Prof. Damián Rimoldi
          UTN FRH - GLT
          Mayo 2025

*/
#include <Wire.h>
#include <Adafruit_MPU6050.h>
#include <Adafruit_Sensor.h>

Adafruit_MPU6050 mpu;

// Variables para acumular los ángulos de inclinación
float angleX = 0;
float angleY = 0;
float angleZ = 0;

// Variable para almacenar el tiempo previo
unsigned long lastTime;

void setup() {
  Serial.begin(57600);  // Reducir velocidad de transmisión
  while (!Serial)
    delay(10);

  if (!mpu.begin()) {
    Serial.println("No se encontró MPU6050, verifique la conexión!");
    while (1)
      yield();
  }

  mpu.setAccelerometerRange(MPU6050_RANGE_8_G);
  mpu.setGyroRange(MPU6050_RANGE_500_DEG);
  mpu.setFilterBandwidth(MPU6050_BAND_21_HZ);

  Serial.println("MPU6050 listo!");
  
  // Inicializar el tiempo previo
  lastTime = millis();
}

void loop() {
  sensors_event_t a, g, temp;
  mpu.getEvent(&a, &g, &temp);

  // Calcular el tiempo transcurrido (dt) en segundos
  unsigned long currentTime = millis();
  float dt = (currentTime - lastTime) / 1000.0;
  lastTime = currentTime;

  // Acumular los ángulos de rotación basados en las velocidades angulares
  angleX += g.gyro.x * dt;
  angleY += g.gyro.y * dt;
  angleZ += g.gyro.z * dt;

  // Enviar datos acumulados en una sola línea separados por comas
  Serial.print(a.acceleration.x); Serial.print(",");
  Serial.print(a.acceleration.y); Serial.print(",");
  Serial.print(a.acceleration.z); Serial.print(",");
  Serial.print(angleX); Serial.print(",");
  Serial.print(angleY); Serial.print(",");
  Serial.println(angleZ);  // Terminar la línea con un salto de línea

  Serial.flush();  // Asegurarse de que todos los datos se enviaron
  delay(50);  // Reducir el tiempo de espera entre envíos de datos
}

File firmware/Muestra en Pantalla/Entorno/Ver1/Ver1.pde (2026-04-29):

/*
  Autor:  Prof. Damián Rimoldi
          UTN FRH - GLT
          Mayo 2025

*/
import processing.serial.*;

Serial myPort;  // Puerto serie
String[] data;  // Datos recibidos
float ax, ay, az, gx, gy, gz;  // Aceleración y giroscopio

float alpha = 0.9;  // Factor de suavizado (entre 0 y 1)

void setup() {
  size(800, 600, P3D);
  frameRate(60);

  String portName = "COM6";  // Puerto donde está conectado el ESP32
  myPort = new Serial(this, portName, 57600);  // Reducir velocidad de transmisión
  myPort.buffer(1024);  // Aumentar el buffer a 1024 bytes
  myPort.bufferUntil('\n');
}

void draw() {
  background(200);

  // Dibujar el cohete
  pushMatrix();
  translate(width/2 , height/2);
  rotateZ(gy);
  rotateY(gx);
  rotateX(gz);
  fill(255, 0, 0);
  box(50, 200, 50);
  popMatrix();
}

void serialEvent(Serial myPort) {
  String input = myPort.readStringUntil('\n');
  input = trim(input);
  data = split(input, ',');

  if (data.length == 6) {
    try {
      ax = lerp(ax, float(data[0]), alpha);
      ay = lerp(ay, float(data[1]), alpha);
      az = lerp(az, float(data[2]), alpha);
      gx = lerp(gx, float(data[3]), alpha);
      gy = lerp(gy, float(data[4]), alpha);
      gz = lerp(gz, float(data[5]), alpha);
    } catch (Exception e) {
      println("Error en la conversión de datos: " + e);
    }
  } else {
    println("Datos incompletos recibidos");
    delay(50);  // Retraso para evitar acumulación de datos
  }
}

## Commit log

2026-04-16 Add initial hardware design: Onboard Computer and Earth Station KiCad projects
    [Earth_Station.kicad_pcb, Earth_Station.kicad_sch, Onboard_Comp.kicad_pcb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]
2026-04-17 Reorganize Onboard Computer KiCad project structure
    [Control.kicad_sch, Onboard_Comp.kicad_pcb, Onboard_Comp.kicad_sch]
2026-04-17 Reorganize Earth Station KiCad project structure
    [Earth_Station.kicad_pcb, Earth_Station.kicad_sch]
2026-04-19 Add Onboard Computer Rev A fabrication outputs
    [Onboard_Comp-B_Cu.gbr, Onboard_Comp-B_Mask.gbr, Onboard_Comp-B_Paste.gbr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]
2026-04-19 Add documentation structure for hardware outputs and technical docs
    [Control.kicad_sch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]
2026-04-19 Add settings structure for hardware outputs and technical docs
    [Earth_Station.kicad_pcb]
2026-04-29 Agrego firmware de prueba
2026-04-29 Actualizo README.md general con la descripcion del firmware agregado
2026-04-29 Agrego documentacion de la arquitectura del sistema
